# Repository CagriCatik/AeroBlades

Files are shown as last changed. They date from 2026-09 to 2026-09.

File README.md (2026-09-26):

# ⚔️ AeroBlades: 3D-Printed FPV Cruiser Fleet & Hybrid VTOL Systems







> **AeroBlades** is a unified hangar, master catalog, and flight guide for the high-performance family of 3D-printed mini-sized FPV cruisers and experimental hybrid VTOL aircraft designed by **Olivier_C** on [RCGroups](https://www.rcgroups.com/forums/showthread.php?4223695-Rifter-Sabre-Scimitar-mini-sized-FPV-cruisers).
>
> Inspired by the distinctive bladed weapons that give each airframe its name (*Urumi, Sabre, Scimitar, Sica, and Rifter*), **AeroBlades** standardizes all CAD models, 3D printing stage files, BOMs, slicing presets, and flight logs into a single comprehensive repository.
>
> Every project in this repository is organized into a standardized, production-ready directory layout:
> * 🖨️ **`3D_Print_Files/`**: Categorized by assembly stage (`01_Fuselage`, `02_Wings`, `03_Tail_and_Stabs` / `Nacelles`, `04_Internal_Plates`, `05_Canopy`, `Extras`).
> * 📐 **`CAD_Source_STEP/`** or **`CAD_Source_Fusion/`**: Parametric STEP and native Fusion 360 (`.f3d`) files for custom CAD modifications.
> * 🖼️ **`media/`**: High-resolution photography of assembled airframes and slicer bed placement guides.
> * 📊 **`*.ods`**: Master spreadsheets with print times, gram weights, and layer profiles.
> * 📦 **`archives/`**: Original source zip distribution packages preserved as pristine backups.

---

## ⚡ Quick Navigation

1. [📊 Master Fleet Comparison Matrix](#-master-fleet-comparison-matrix)
2. [🛸 Urumi](#1-urumi-experimental-hybrid-vtol--quadplane) — Experimental quad-motor tailsitter VTOL / Interceptor (571g)
3. [🛩️ Mini Rifter](#2-mini-rifter-ultra-compact-fpv-cruiser) — Ultra-compact single-pusher cruiser (314g)
4. [🛩️ Rifter 3](#3-rifter-3-high-endurance-v-tail-cruiser) — Third-generation long-endurance cruiser (430g)
5. [🗡️ Sabre](#4-sabre-high-speed-twin-tractor-plank) — Twin-tractor high-speed plank (476g)
6. [🦅 Scimitar 3](#5-scimitar-3-swept-wing-flying-wing) — Third-generation swept flying wing (438g)
7. [⚔️ Sica](#6-sica-flagship-twin-tractor-heavy-cruiser) — Flagship twin-tractor heavy cruiser with COB LEDs (746g)
8. [📦 Common Hardware Ecosystem](#-common-hardware-ecosystem) — SCM camera mounts, DJI O3 cages, canopy spring locks
9. [🔩 Fleet-Wide Carbon Spar Procurement Matrix](#-fleet-wide-carbon-spar-procurement-matrix)
10. [🖨️ Standardized Slicing Profiles Cheat Sheet](#-standardized-slicing-profiles-cheat-sheet)
11. [🛠️ Fleet Best Practices & Engineering Guides](#️-fleet-best-practices--engineering-guides)
12. [📂 Repository Directory Structure](#-repository-directory-structure)
13. [📌 Citation & Forum Thread](#-citation--forum-thread)

---

## 📊 Master Fleet Comparison Matrix

```mermaid
graph TD
    FLEET["⚔️ <b>AeroBlades 3D-Printed Fleet</b><br/><i>(Designed by Olivier_C)</i>"]
    
    FLEET --> PUSHER["<b>Single Pusher Cruisers</b>"]
    FLEET --> TWIN["<b>Twin Tractor Cruisers</b>"]
    FLEET --> VTOL["<b>Hybrid VTOL Systems</b>"]
    FLEET --> COMMON["<b>Hardware Ecosystem</b>"]
    
    PUSHER --> MR["🛩️ <b>Mini Rifter</b> (314g)<br/>Ultra-compact park cruiser"]
    PUSHER --> R3["🛩️ <b>Rifter 3</b> (430g)<br/>Long-endurance V-tail glider"]
    PUSHER --> SC3["🦅 <b>Scimitar 3</b> (438g)<br/>Swept acrobatic wing"]
    
    TWIN --> SAB["🗡️ <b>Sabre</b> (476g)<br/>High-speed carving plank (120+ km/h)"]
    TWIN --> SIC["⚔️ <b>Sica</b> (746g)<br/>Flagship heavy twin (COB LEDs)"]
    
    VTOL --> URU["🛸 <b>Urumi</b> (571g)<br/>Quad-motor tailsitter VTOL"]
    COMMON --> COM["📦 <b>Common Hardware</b><br/>SCM mounts, DJI O3 cages, locks"]
```

| Aircraft | Category | Propulsion | Plastic Wt. | Print Time | Carbon Spars | Controls | Best Suited For | Files / Project |
| :--- | :--- | :--- | :---: | :---: | :--- | :--- | :--- | :---: |
| [**Urumi**](#1-urumi-experimental-hybrid-vtol--quadplane) | Hybrid VTOL | Quad Motor (4× 2207–2806, 7" props) | **571 g** | 26h 30m | 4× 6×284mm | Differential Thrust (No control surfaces) | Vertical takeoff/landing, hover-to-cruise transition | [📂 `projects/Urumi/`](projects/Urumi/) |
| [**Mini Rifter**](#2-mini-rifter-ultra-compact-fpv-cruiser) | Compact Cruiser | Single Pusher (1806–2204, 4"–5" prop) | **314 g** | 19h 18m | Front: 6×600mm<br>Rear: 6×260mm | Ailerons + Stabs | Park flying, tight spaces, ultra-portability | [📂 `projects/Mini_Rifter/`](projects/Mini_Rifter/) |
| [**Rifter 3**](#3-rifter-3-high-endurance-v-tail-cruiser) | Long-Range Cruiser | Single Pusher (2207–2806, 6"–7" prop) | **430 g** | 31h 40m | Front: 8×800mm<br>Rear: 6×400mm<br>Fuselage: 2× 6×135mm | Ailerons + V-Tail | High-efficiency glide, long range, relaxed cruising | [📂 `projects/Rifter_3/`](projects/Rifter_3/) |
| [**Sabre**](#4-sabre-high-speed-twin-tractor-plank) | Fast FPV Plank | Twin Tractor (2× 1404–1806, 4"–5" props)| **476 g** | 45h 41m | Front: 6×680mm<br>Rear: 6×320mm | 2 Elevons | Low-level carving, high top speed, pitch locked | [📂 `projects/Sabre/`](projects/Sabre/) |
| [**Scimitar 3**](#5-scimitar-3-swept-wing-flying-wing)| Flying Wing | Single Pusher (2207–2306, 5"–6" prop) | **438 g** | 21h 02m | Main: 8×750mm<br>Front: 2× 6×150mm | 2 Elevons | High agility, zero fuselage drag, aerobatics | [📂 `projects/Scimitar_3/`](projects/Scimitar_3/) |
| [**Sica**](#6-sica-flagship-twin-tractor-heavy-cruiser) | Heavy Flagship | Twin Tractor (2× 2207–2806, 6"–7" props)| **746 g** | 39h 59m | Front: 8×1000mm<br>Rear: 6×700mm<br>Tail: 2× 8×330mm | Ailerons + Twin Rudders + Elevator | Max payload, gimbal mounts, night flights (COB LED) | [📂 `projects/Sica/`](projects/Sica/) |
| [**Common**](#-common-hardware-ecosystem) | Hardware Ecosystem | Modular (Canopy Locks, SCM, O3 Cages) | Variable | - | - | - | Universal hardware across all airframes | [📂 `projects/Common/`](projects/Common/) |

---

## 🛩️ Detailed Aircraft Profiles

### 1. Urumi: Experimental Hybrid VTOL / Quadplane





> **Urumi** is an experimental hybrid VTOL aircraft combining vertical helicopter hovering with high-speed wing-borne forward flight. Featuring four 22° dihedral wings, four brushless motors, a tilting servo camera, and **no moving control surfaces**, Urumi is steered entirely via differential thrust.

| Top View | Front View |
| :---: | :---: |
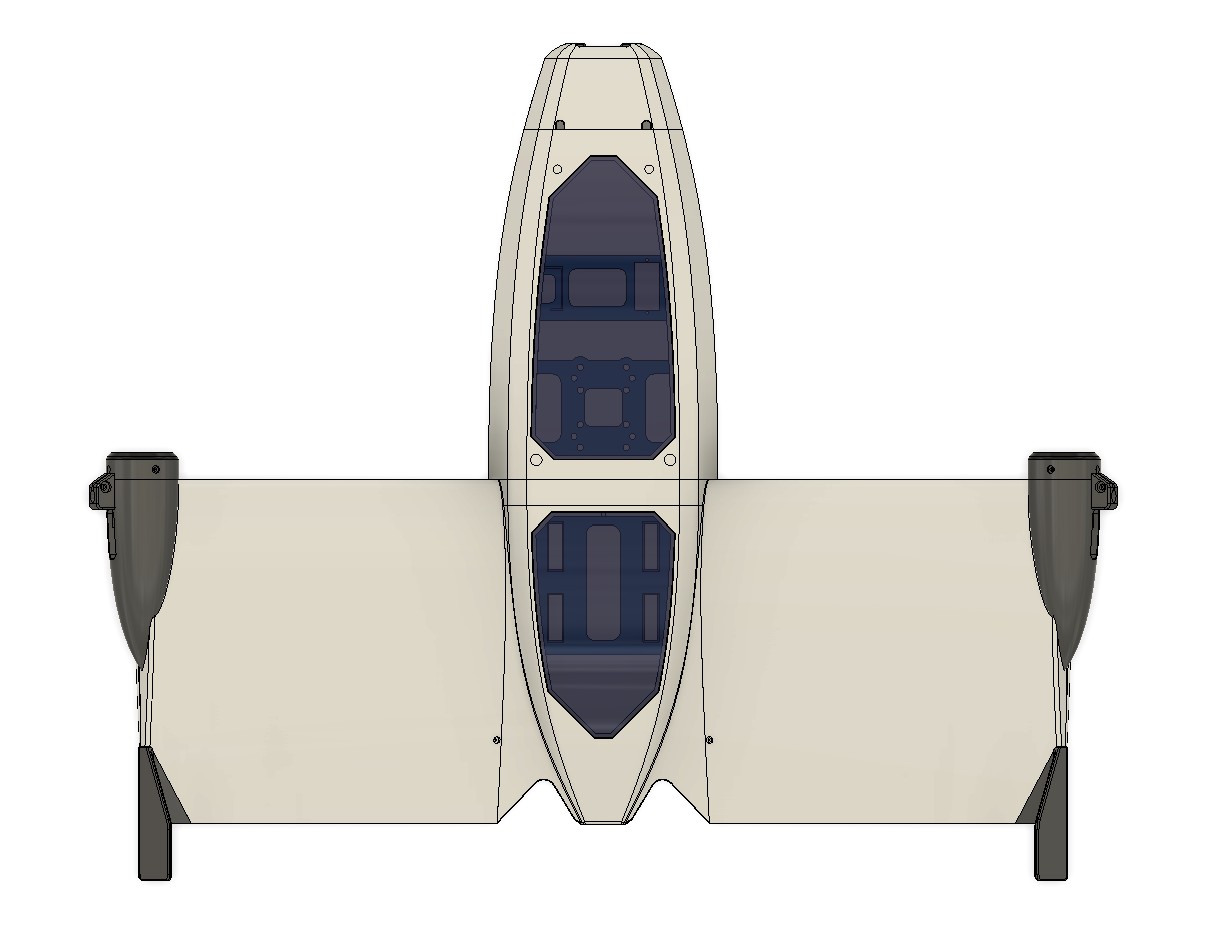
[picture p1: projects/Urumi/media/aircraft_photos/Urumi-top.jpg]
Urumi Top
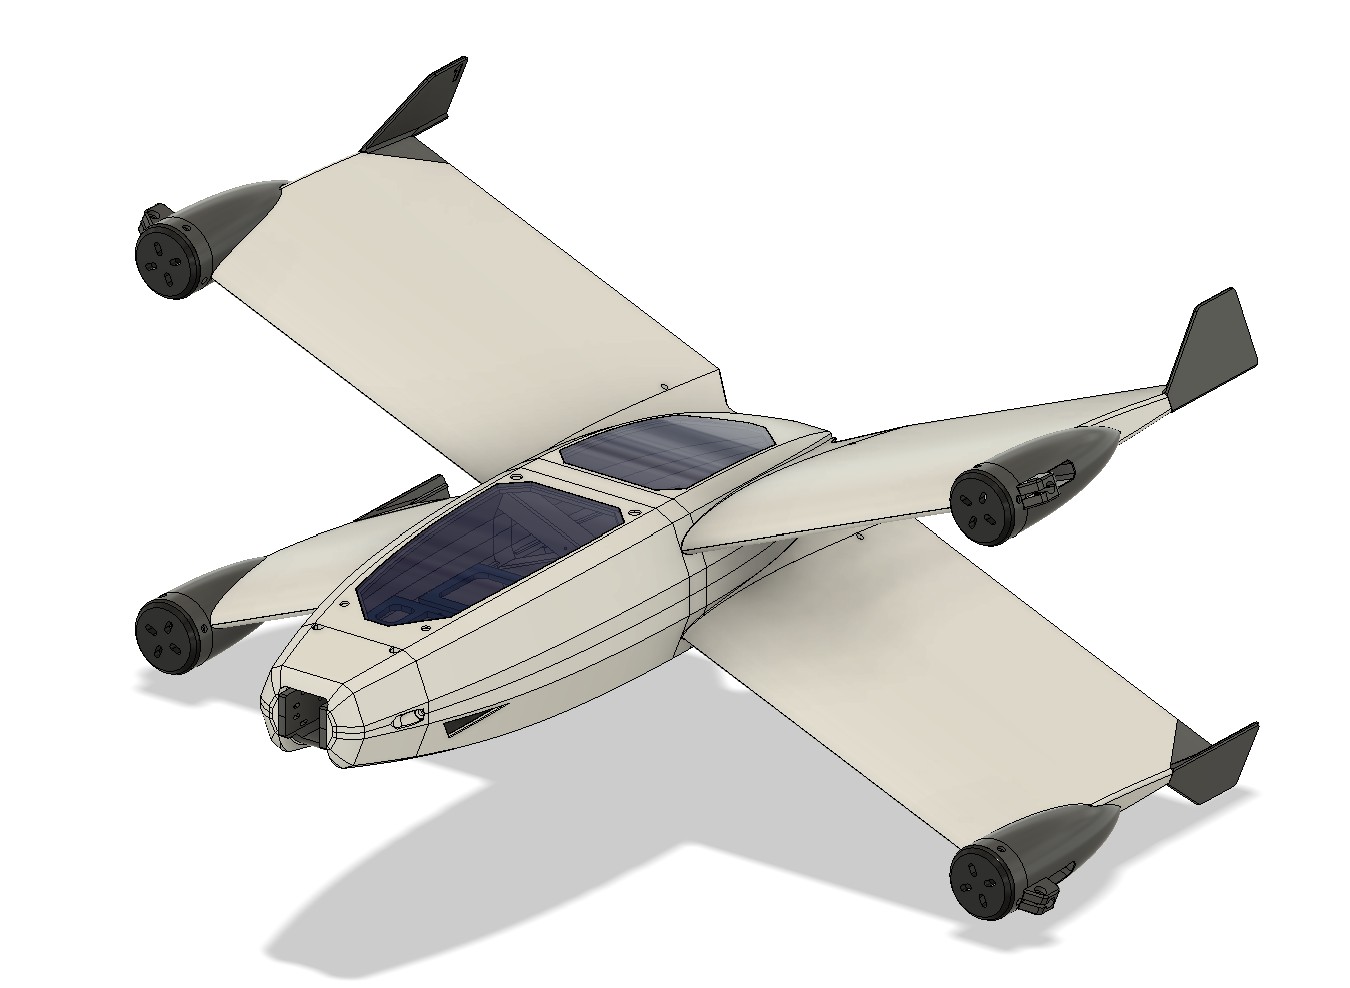
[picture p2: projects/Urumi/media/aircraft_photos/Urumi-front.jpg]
Urumi Front
|  |  |
| **Side Profile** | **Disassembled Airframe & Removable Wings** |
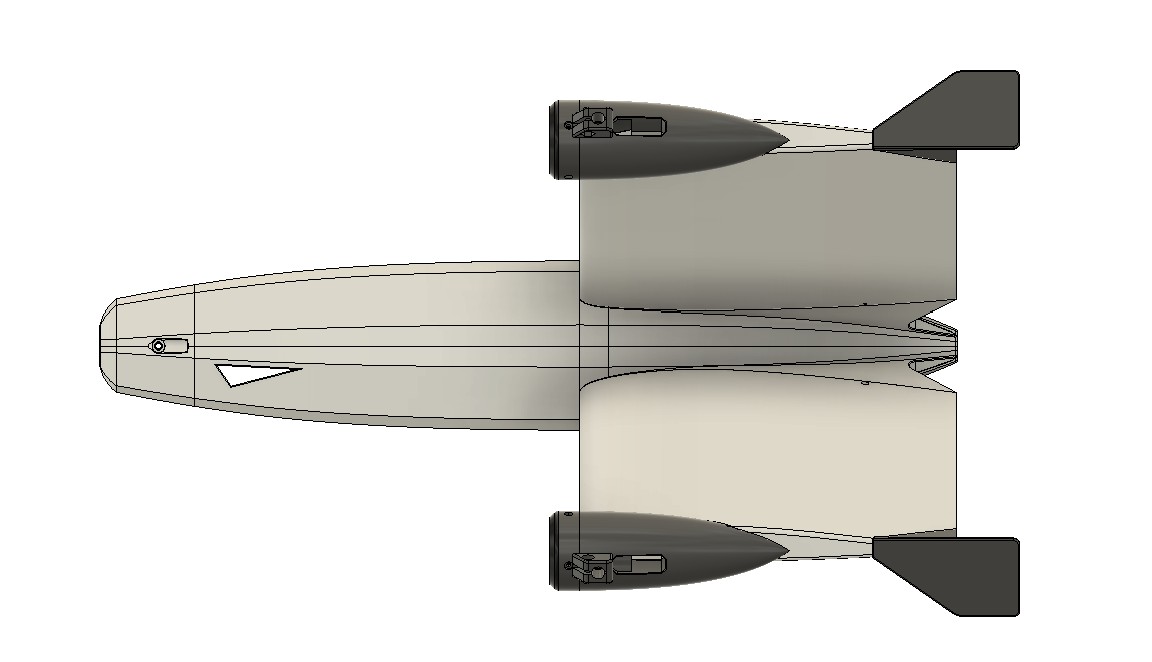
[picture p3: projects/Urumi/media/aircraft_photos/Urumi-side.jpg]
Urumi Side
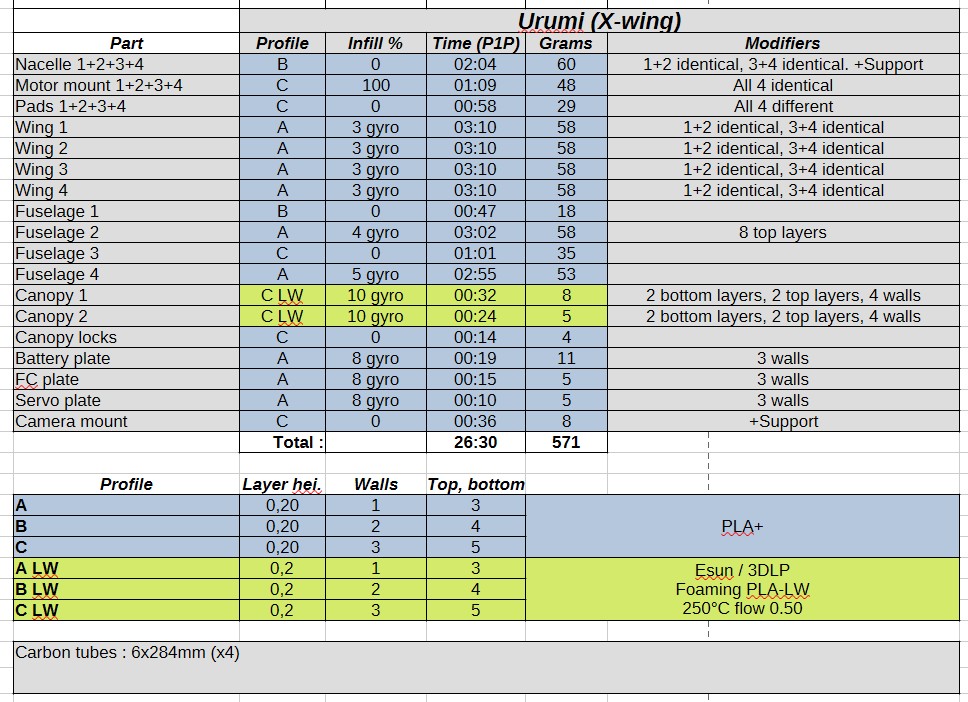
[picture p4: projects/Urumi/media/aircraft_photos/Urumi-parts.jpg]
Urumi Parts
|  |  |

* **Key Specifications**:
  * **Plastic Print Weight**: 571 g (Dry weight with FPV gear: 1035 g, AUW: ~1215 g with 4S 1500mAh)
  * **Print Time**: 26h 30m (Bambu Lab P1P)
  * **Propulsion**: 4× 2207 (1800–1950KV on 4S) or 2806.5 motors with 7" propellers
  * **Battery**: 4S 1500mAh 100C LiPo (~180g)
  * **Transition Airspeed**: 70 – 80 km/h
  * **Carbon Spars Required**: 4× 6.0 mm × 284 mm (forms central X-frame)
* **Available Resources**:
  * 🖨️ **3D Print Files**: [`projects/Urumi/3D_Print_Files/`](projects/Urumi/3D_Print_Files/)
    * `01_Fuselage/` — Fuselage 1, 2, 3, 4
    * `02_Wings/` — Wing 1-2, Wing 3-4 (with mirroring)
    * `03_Nacelles_and_Mounts/` — Nacelles 1-4, Motor mounts 1-4, Landing pads 1-4
    * `04_Internal_Plates/` — Battery plate, FC plate, Servo plate, Camera mount
    * `05_Canopy/` — Canopy 1 & 2, Canopy locks
    * `Extras/` — 0.5mm tighter motor mounts, Wing roots 1-4
  * 📐 **Slicer Placement Guides**: [`projects/Urumi/media/slicer_placement/`](projects/Urumi/media/slicer_placement/) (11 bed photos)
  * 🛠️ **CAD STEP Models**: [`projects/Urumi/CAD_Source_STEP/`](projects/Urumi/CAD_Source_STEP/) (19 STEP models)
  * 📚 **In-Depth Documentation Suite**: [`projects/Urumi/docs/`](projects/Urumi/docs/)
    * [01: Hardware Electronics & Configuration Software](projects/Urumi/docs/01_HARDWARE_ELECTRONICS.md)
    * [02: Hardware Parts, Mechanical Structure & Filaments](projects/Urumi/docs/02_HARDWARE_PARTS_AND_MECHANICAL.md)
    * [03: 3D Printing Guide & Master Slicer Profiles](projects/Urumi/docs/03_PRINT_GUIDE_AND_PROFILES.md)
    * [04: Airframe Assembly & Wiring Guide](projects/Urumi/docs/04_ASSEMBLY_AND_WIRING.md)
    * [05: INAV Hybrid VTOL Flight Manual](projects/Urumi/docs/05_INAV_FLIGHT_MANUAL.md)
    * [06: Designer Flight Logs & Video Transcripts](projects/Urumi/docs/06_DESIGNER_FLIGHT_LOGS_AND_VIDEO_TRANSCRIPTS.md)
  * 🎬 **Videos**: [Part 1 (Conception)](https://www.youtube.com/watch?v=R3-GTveqTRI) | [Part 2 (Crash Investigation)](https://www.youtube.com/watch?v=sHy94xdoC1A) | [Part 3 (Wind Handling)](https://www.youtube.com/watch?v=J87EU8D0PFA)

---

### 2. Mini Rifter: Ultra-Compact FPV Cruiser





> **Mini Rifter** is a scaled-down, ultra-portable edition of the Rifter cruiser platform. Designed for agile cruising, park flying, and efficient long endurance on small battery packs.

| Top View | Front View |
| :---: | :---: |
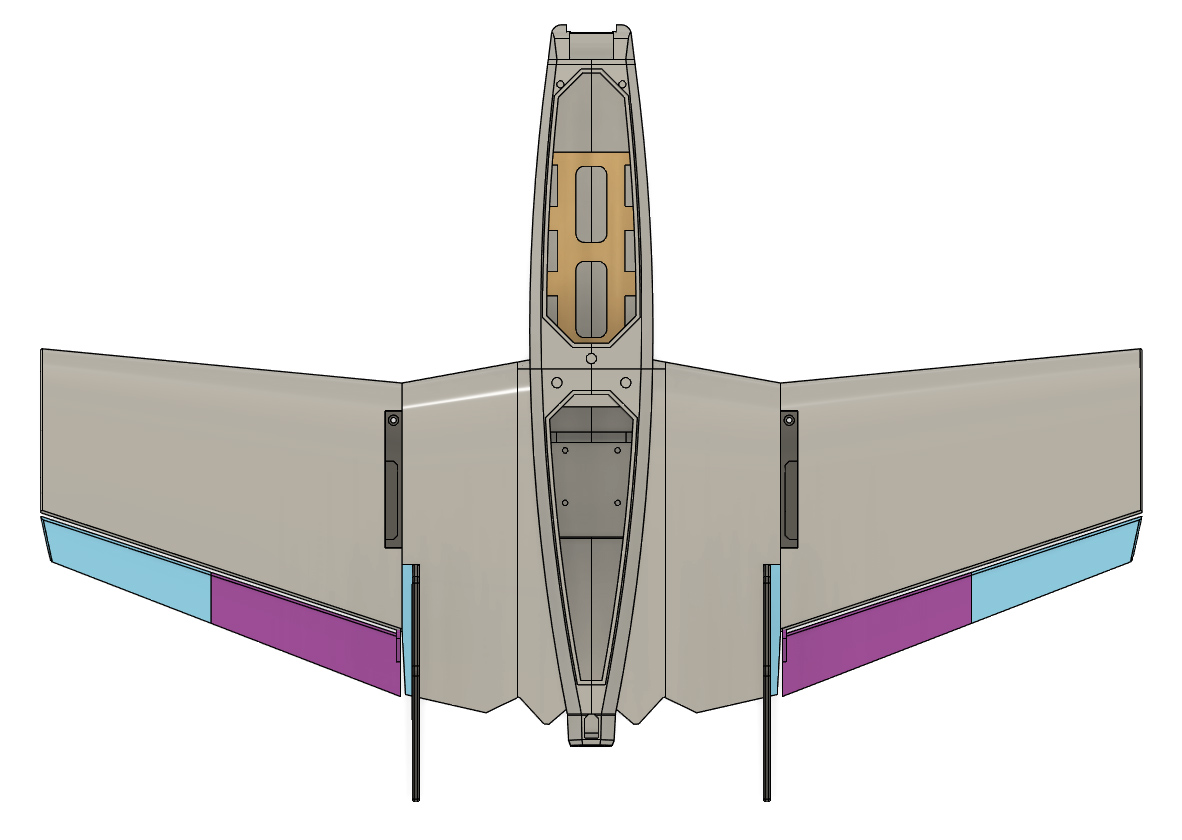
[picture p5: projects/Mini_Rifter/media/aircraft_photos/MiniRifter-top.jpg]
Mini Rifter Top
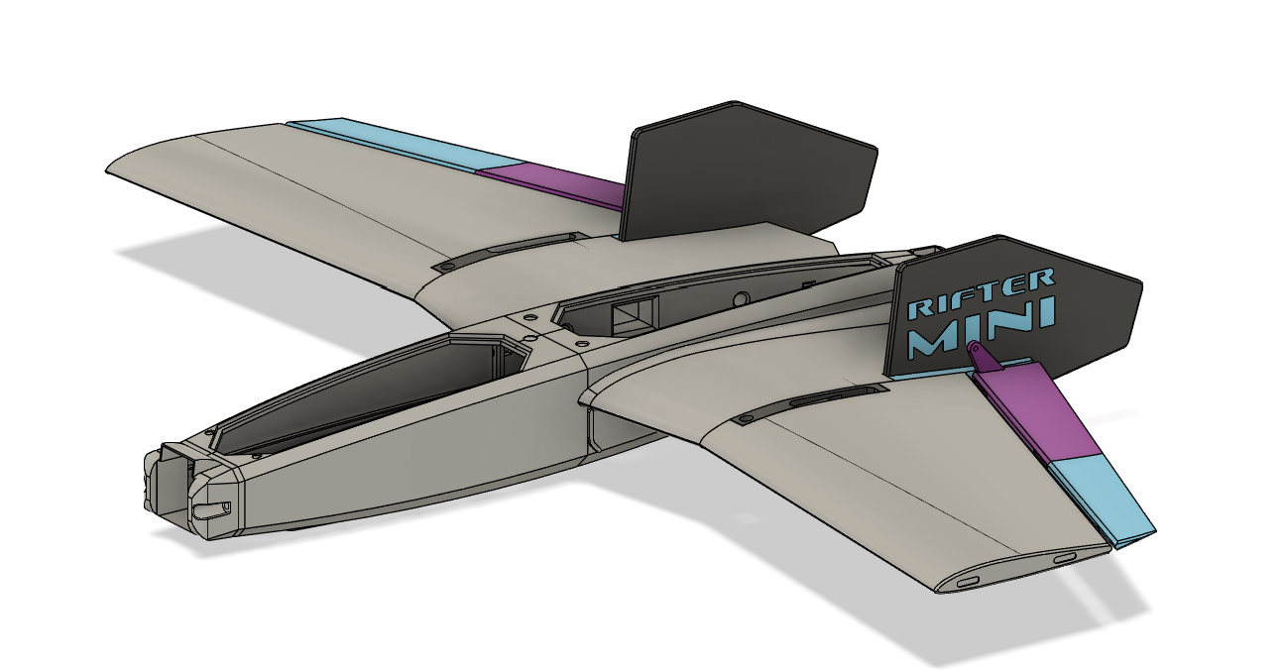
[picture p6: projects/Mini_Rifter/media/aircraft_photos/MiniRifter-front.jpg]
Mini Rifter Front
|  |  |
| **Side Profile** | **Disassembled Airframe & Parts** |
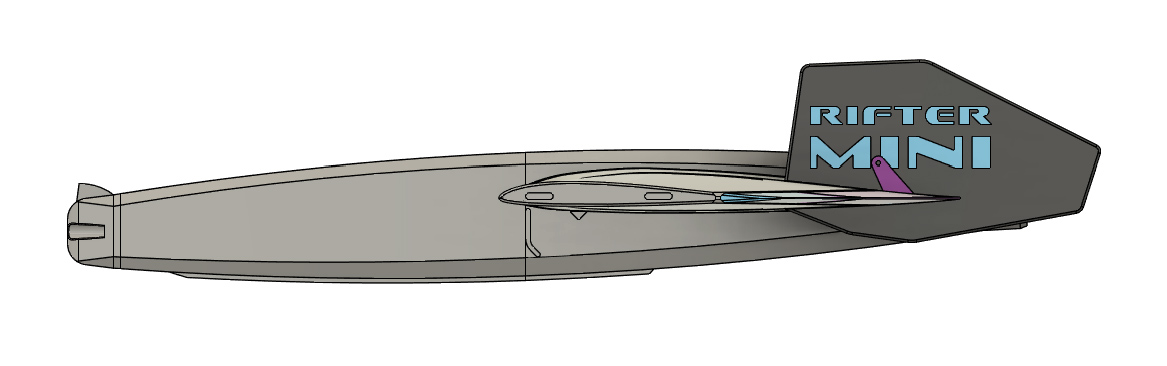
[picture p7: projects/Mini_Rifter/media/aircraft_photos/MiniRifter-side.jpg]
Mini Rifter Side
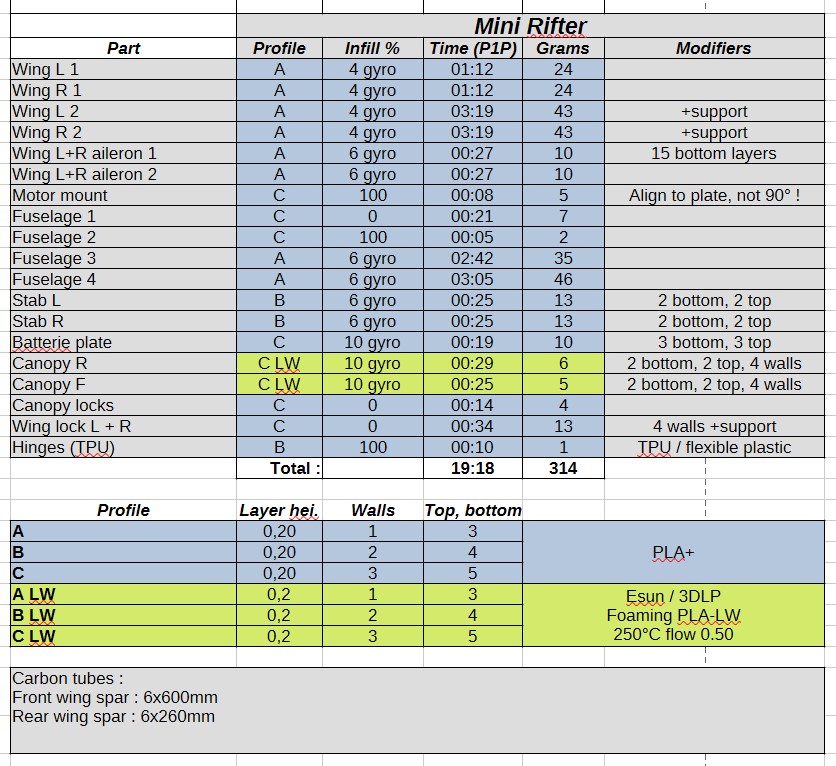
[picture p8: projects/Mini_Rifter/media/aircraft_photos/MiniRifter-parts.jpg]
Mini Rifter Parts
|  |  |

* **Key Specifications**:
  * **Plastic Print Weight**: 314 g
  * **Print Time**: 19h 18m (Bambu Lab P1P)
  * **Propulsion**: Single rear pusher motor (1806–2204), 4"–5" prop
  * **Battery**: 3S 18650 Li-ion pack or 3S/4S 1300–1500mAh LiPo
  * **Carbon Spars Required**: Front 6.0 mm × 600 mm, Rear 6.0 mm × 260 mm
* **Available Resources**:
  * 🖨️ **3D Print Files**: [`projects/Mini_Rifter/3D_Print_Files/`](projects/Mini_Rifter/3D_Print_Files/)
    * `01_Fuselage/` — Fuselage 1, 2, 3, 4, F3F4 pins
    * `02_Wings/` — Wings 1 & 2 (L/R), Ailerons 1 & 2 (L/R), Wing locks
    * `03_Tail_and_Stabs/` — Wing Stabs (L/R), Motor mount
    * `04_Internal_Plates/` — Battery plate, TPU hinges
    * `05_Canopy/` — Canopy F & R, Canopy locks
    * `Extras/` — SCM camera nose, no-holes nose, wingtips, external DJI O3 pod
  * 📐 **Slicer Placement Guides**: [`projects/Mini_Rifter/media/slicer_placement/`](projects/Mini_Rifter/media/slicer_placement/) (9 bed photos)
  * 🛠️ **CAD STEP Models**: [`projects/Mini_Rifter/CAD_Source_STEP/`](projects/Mini_Rifter/CAD_Source_STEP/) (16 STEP files)
  * 🎬 **Video**: [Mini Rifter Flight Test on YouTube](https://www.youtube.com/watch?v=fl-8yHl3snQ)

---

### 3. Rifter 3: High-Endurance V-Tail Cruiser





> **Rifter 3** is the mature, third-generation evolution of the Rifter single-motor pusher cruiser. Boasting a large high-aspect-ratio wing, dedicated fuselage bays, and modular carbon reinforcement, it delivers exceptional glide ratios and long-range cruising.

| Top View | Front View |
| :---: | :---: |
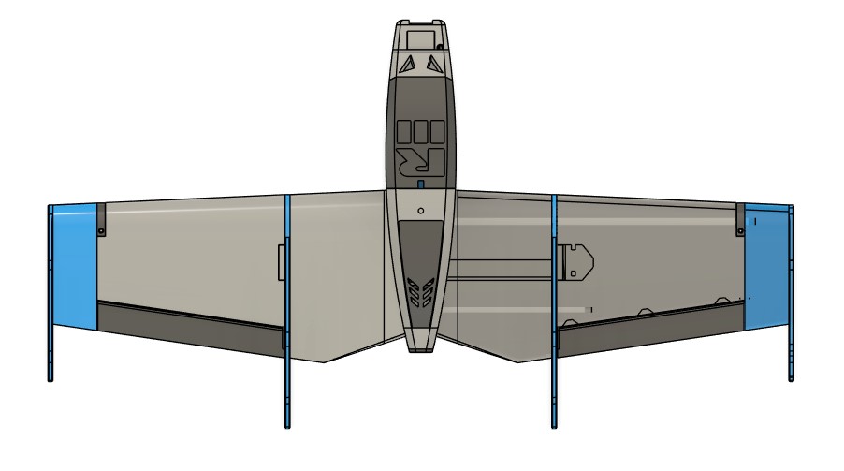
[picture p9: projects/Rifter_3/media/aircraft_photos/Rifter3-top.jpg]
Rifter 3 Top
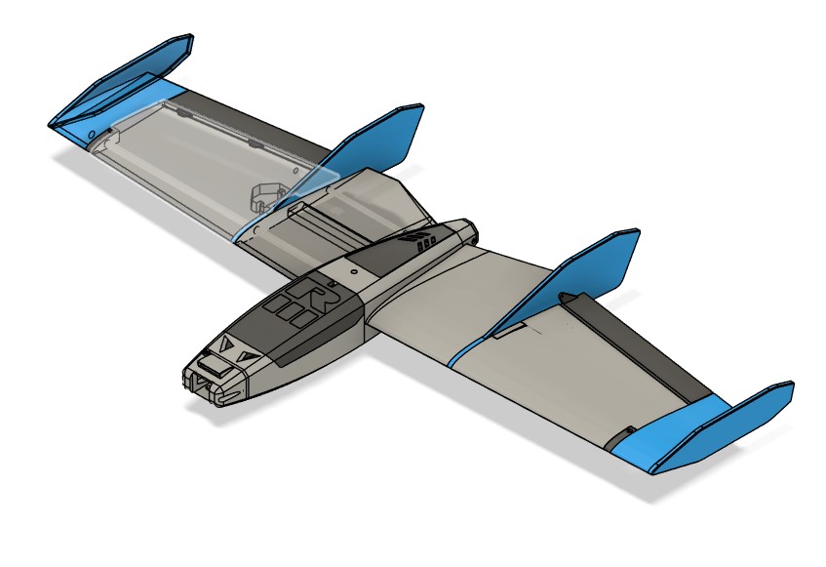
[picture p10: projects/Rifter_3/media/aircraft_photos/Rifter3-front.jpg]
Rifter 3 Front
|  |  |
| **Side Profile** | **Disassembled Airframe & Parts** |
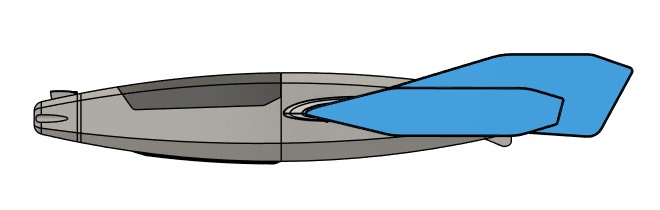
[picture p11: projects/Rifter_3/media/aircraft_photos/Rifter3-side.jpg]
Rifter 3 Side
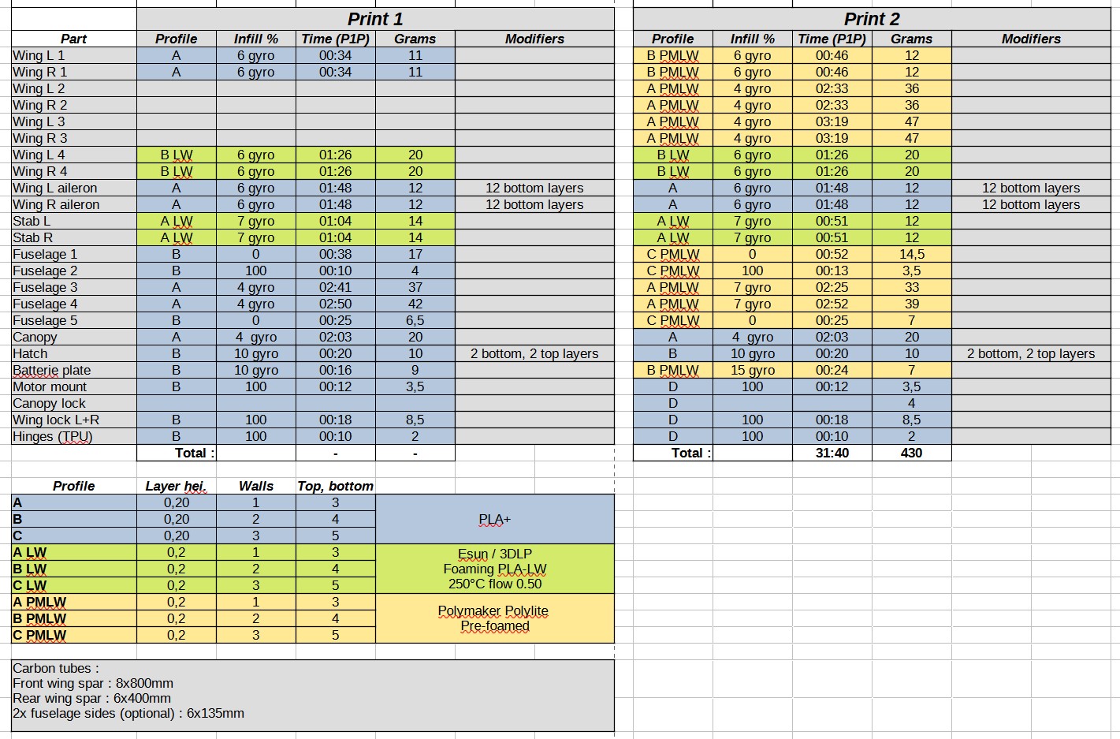
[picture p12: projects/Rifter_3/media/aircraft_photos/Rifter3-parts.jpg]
Rifter 3 Parts
|  |  |

* **Key Specifications**:
  * **Plastic Print Weight**: 430 g
  * **Print Time**: 31h 40m (Bambu Lab P1P)
  * **Propulsion**: Single rear pusher motor (2207–2806.5), 6"–7" prop
  * **Battery**: 4S 18650 / 21700 Li-ion pack (up to 4000–5000mAh) or 4S LiPo
  * **Carbon Spars Required**: Front 8.0 mm × 800 mm, Rear 6.0 mm × 400 mm, Fuselage (optional) 2× 6.0 mm × 135 mm
* **Available Resources**:
  * 🖨️ **3D Print Files**: [`projects/Rifter_3/3D_Print_Files/`](projects/Rifter_3/3D_Print_Files/)
    * `01_Fuselage/` — Fuselage 1 to 5, Hatch
    * `02_Wings/` — Wings 1 to 4 (L/R), Ailerons (L/R), Wing locks
    * `03_Tail_and_Stabs/` — V-tail Stabs, Motor mount
    * `04_Internal_Plates/` — Battery plate
    * `05_Canopy/` — Canopy, Canopy lock
    * `Extras/` — SCM camera nose, GPS plate
  * 📐 **Slicer Placement Guides**: [`projects/Rifter_3/media/slicer_placement/`](projects/Rifter_3/media/slicer_placement/) (13 bed photos)
  * 🛠️ **CAD STEP Models**: [`projects/Rifter_3/CAD_Source_STEP/`](projects/Rifter_3/CAD_Source_STEP/) (14 STEP files)
  * 🎬 **Videos**: [Rifter 3 Flight Test](https://www.youtube.com/watch?v=L3LojPVs68U) | [Rifter 2 Historic Video](https://www.youtube.com/watch?v=LL8X9GLXXWU)

---

### 4. Sabre: High-Speed Twin-Tractor Plank





> **Sabre** is a fast, aggressive twin-tractor "plank" cruiser. With twin counter-rotating tractor motors mounted on wing nacelles and an un-swept plank wing layout, Sabre delivers blistering acceleration, locked-in pitch stability, and thrilling low-altitude carving.

| Top View | Front View |
| :---: | :---: |
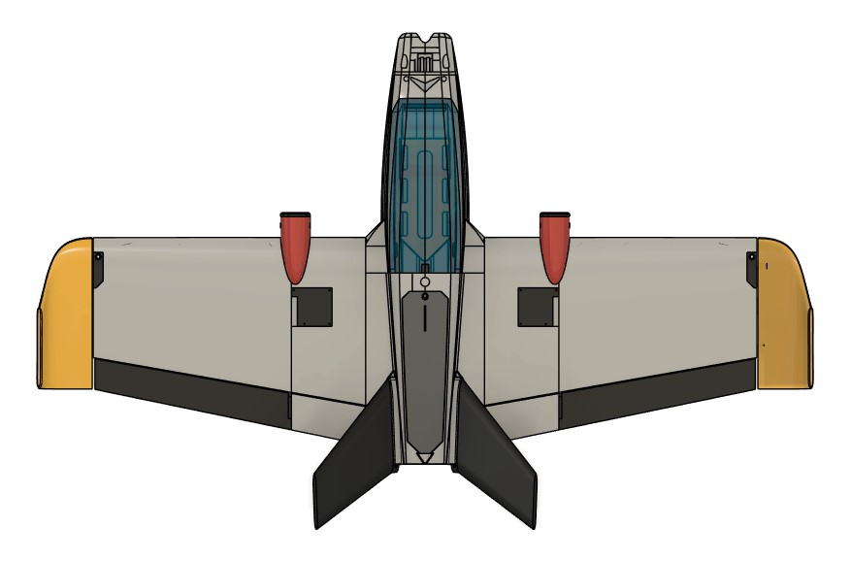
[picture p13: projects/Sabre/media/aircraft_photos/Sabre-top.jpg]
Sabre Top
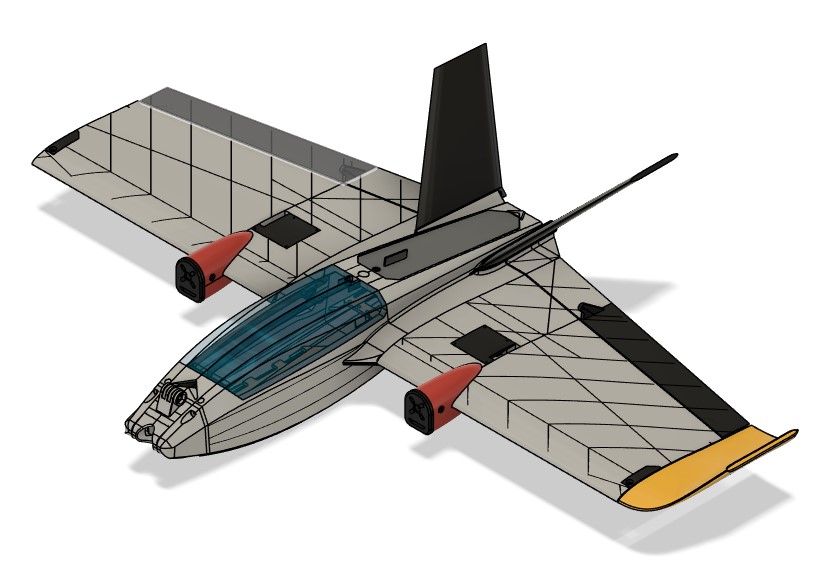
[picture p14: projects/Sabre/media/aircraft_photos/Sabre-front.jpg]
Sabre Front
|  |  |
| **Side Profile** | **Disassembled Airframe & Parts** |
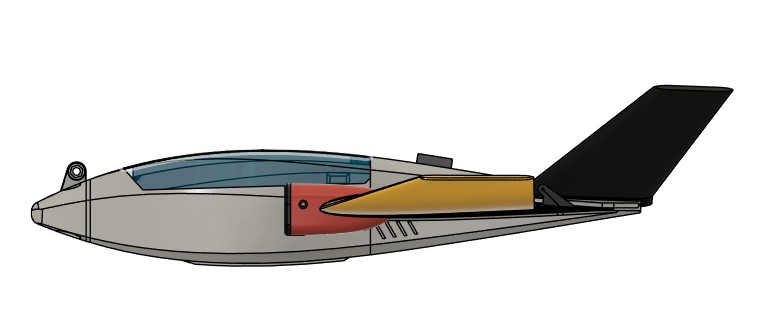
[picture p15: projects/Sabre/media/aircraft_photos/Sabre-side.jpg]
Sabre Side
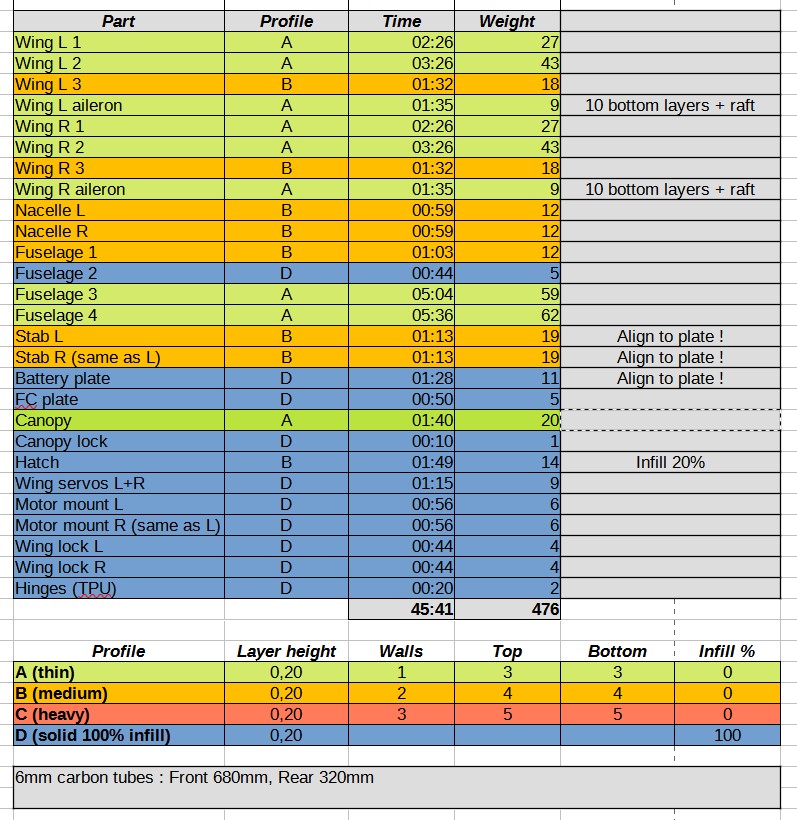
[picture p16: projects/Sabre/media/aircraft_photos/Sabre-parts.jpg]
Sabre Parts
|  |  |

* **Key Specifications**:
  * **Plastic Print Weight**: 476 g
  * **Print Time**: 45h 41m (Bambu Lab P1P)
  * **Propulsion**: Twin tractor motors (2× 1404–1806), 4"–5" counter-rotating props
  * **Battery**: 4S 1500–2200mAh LiPo or 4S 18650 Li-ion pack
  * **Carbon Spars Required**: Front 6.0 mm × 680 mm, Rear 6.0 mm × 320 mm
* **Available Resources**:
  * 🖨️ **3D Print Files**: [`projects/Sabre/3D_Print_Files/`](projects/Sabre/3D_Print_Files/)
    * `01_Fuselage/` — Fuselage 1 to 4, Hatch
    * `02_Wings/` — Wings 1 to 3 (L/R), Ailerons, Locks, Servos
    * `03_Nacelles_and_Mounts/` — Nacelles (L/R), Motor mounts, Stabs
    * `04_Internal_Plates/` — Battery plate, FC plate, TPU hinges
    * `05_Canopy/` — Canopy, Canopy lock
    * `Extras/` — Dedicated GoPro nose, SCM nose
  * 📐 **Slicer Placement Guides**: [`projects/Sabre/media/slicer_placement/`](projects/Sabre/media/slicer_placement/) (21 bed photos)
  * 🛠️ **Parametric Fusion 360 Source Files**: [`projects/Sabre/CAD_Source_Fusion/`](projects/Sabre/CAD_Source_Fusion/) (18 native `.f3d` files)
  * 🎬 **Video**: [Sabre Flight Demonstration on YouTube](https://www.youtube.com/watch?v=Vm1uSv3ZKd4)

---

### 5. Scimitar 3: Swept-Wing Flying Wing





> **Scimitar 3** is a high-performance 3D-printed swept flying wing powered by a central pusher motor. Engineered for clean laminar airflow, fast cruise speeds, and high aerobatic agility with zero fuselage drag.

| Top View | Front View |
| :---: | :---: |
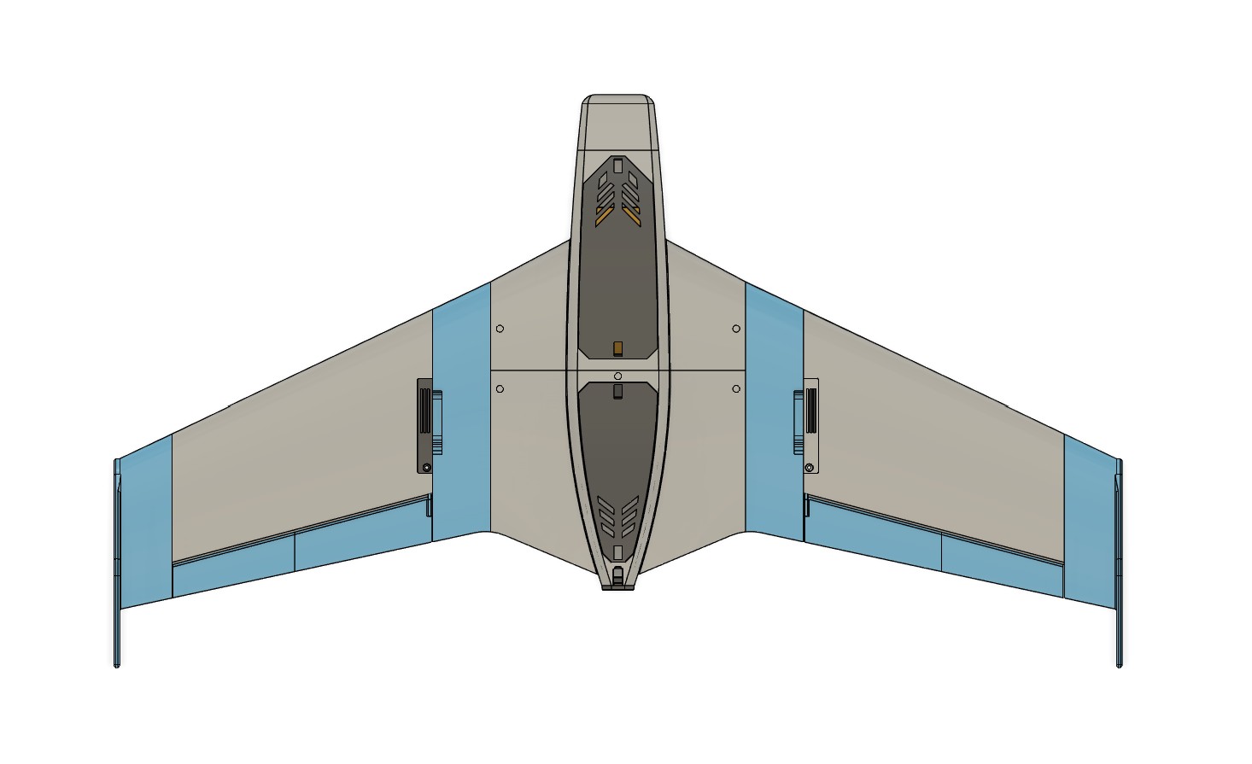
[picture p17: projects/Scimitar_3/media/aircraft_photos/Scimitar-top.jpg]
Scimitar 3 Top
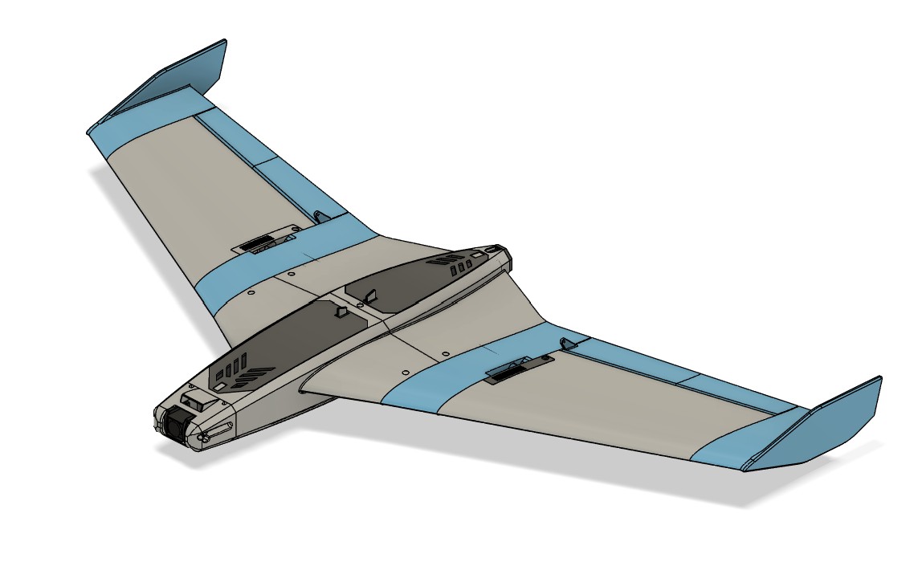
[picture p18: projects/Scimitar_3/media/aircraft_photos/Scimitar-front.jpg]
Scimitar 3 Front
|  |  |
| **Side Profile** | **Disassembled Airframe & Parts** |
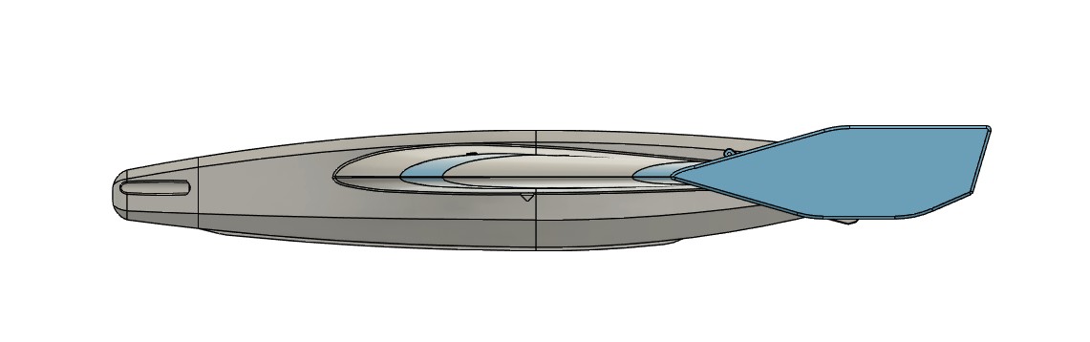
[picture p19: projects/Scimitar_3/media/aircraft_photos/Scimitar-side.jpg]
Scimitar 3 Side
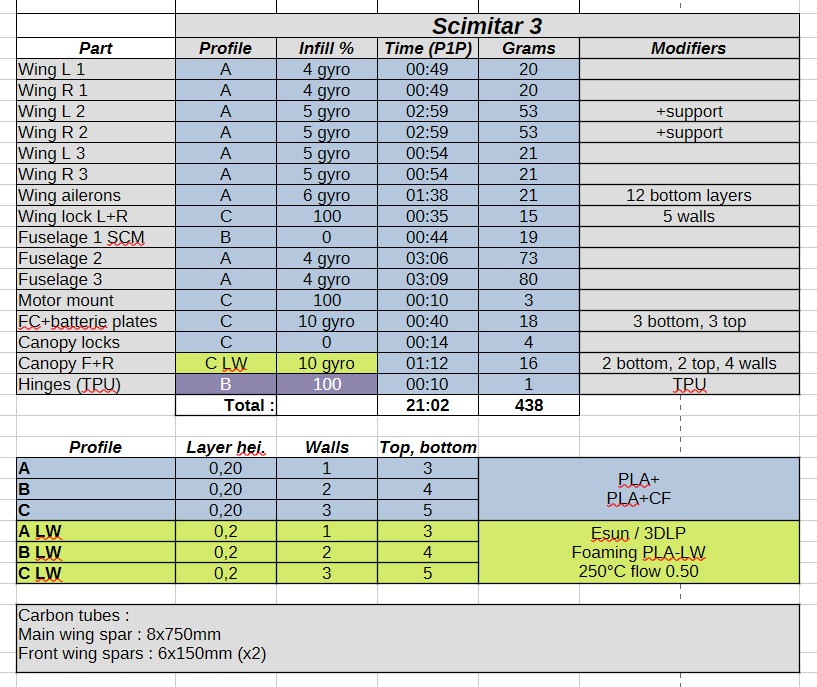
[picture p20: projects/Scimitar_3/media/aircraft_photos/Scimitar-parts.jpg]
Scimitar 3 Parts
|  |  |

* **Key Specifications**:
  * **Plastic Print Weight**: 438 g
  * **Print Time**: 21h 02m (Bambu Lab P1P)
  * **Propulsion**: Single rear pusher motor (2207–2306), 5"–6" prop
  * **Battery**: 4S 1500–2200mAh LiPo or 4S 18650 Li-ion pack
  * **Carbon Spars Required**: Main wing spar 8.0 mm × 750 mm, Front wing spars 2× 6.0 mm × 150 mm
* **Available Resources**:
  * 🖨️ **3D Print Files**: [`projects/Scimitar_3/3D_Print_Files/`](projects/Scimitar_3/3D_Print_Files/)
    * `01_Fuselage/` — Fuselage 1, 1 SCM, 2, 3
    * `02_Wings/` — Wings 1 to 3 (L/R), Elevons, Wing locks
    * `03_Motor_Mount/` — Motor mount 4mm
    * `04_Internal_Plates/` — Battery plate, FC plate, TPU hinges
    * `05_Canopy/` — Canopy F & R, Canopy locks
    * `Extras/` — Extended wingtips (+25mm), centering pin, text canopies
  * 📐 **Slicer Placement Guides**: [`projects/Scimitar_3/media/slicer_placement/`](projects/Scimitar_3/media/slicer_placement/) (11 bed photos)
  * 🛠️ **CAD STEP Models**: [`projects/Scimitar_3/CAD_Source_STEP/`](projects/Scimitar_3/CAD_Source_STEP/) (10 STEP files)
  * 🎬 **Video**: [Scimitar Flying Wing Flight Demonstration](https://www.youtube.com/watch?v=LZn1OF9eK5k)

---

### 6. Sica: Flagship Twin-Tractor Heavy Cruiser





> **Sica** is the flagship heavy long-range cruiser of the fleet. Featuring twin forward tractor motors, a generous fuselage payload cabin, twin vertical stabilizers, and full night-flight COB LED internal channels, Sica is the ultimate endurance platform.

| Top View | Front View |
| :---: | :---: |
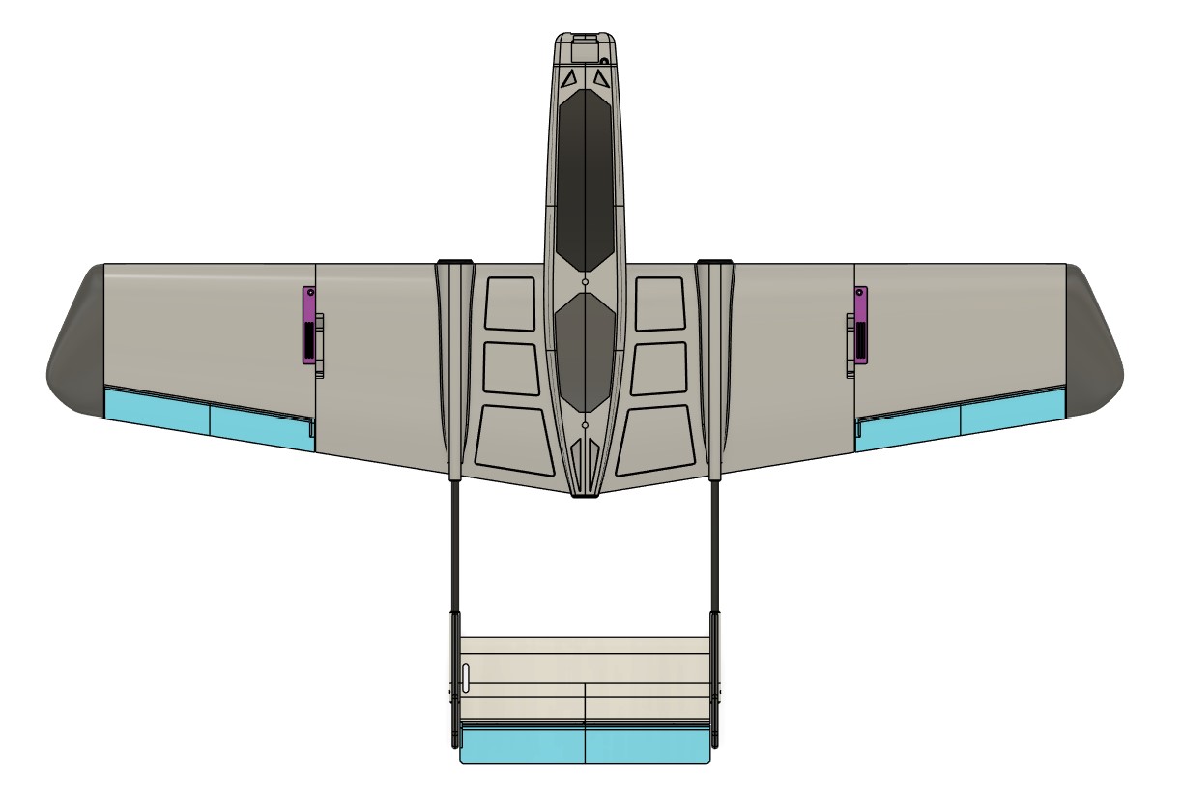
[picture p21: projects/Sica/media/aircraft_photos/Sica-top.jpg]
Sica Top
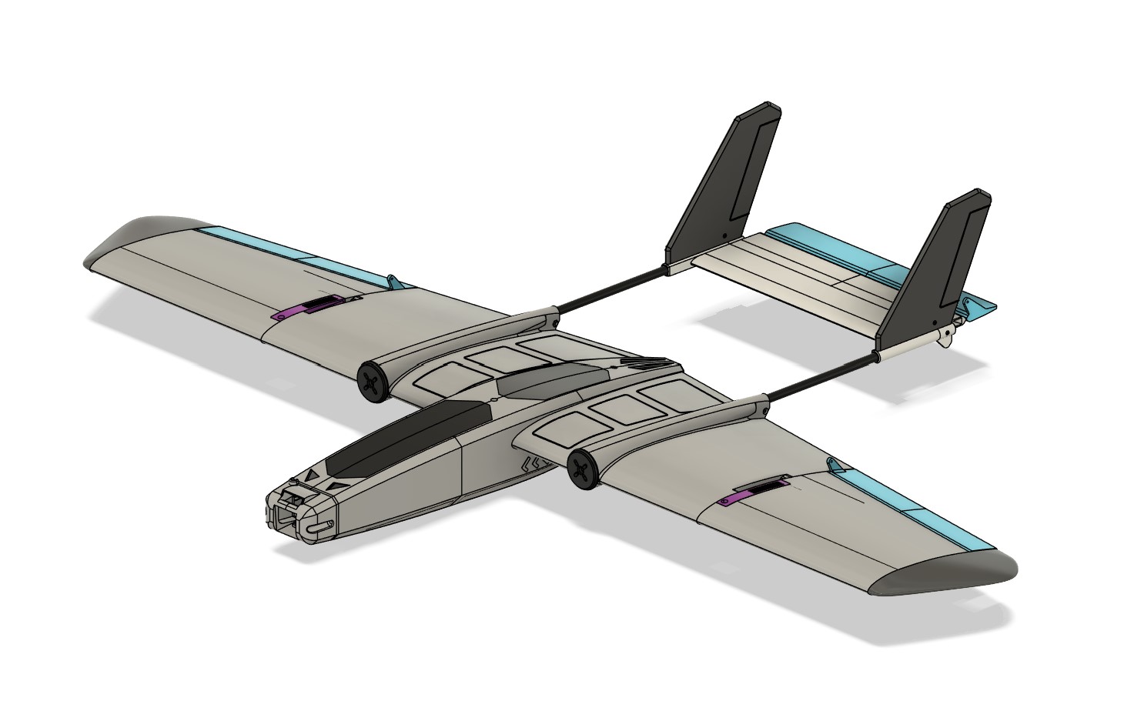
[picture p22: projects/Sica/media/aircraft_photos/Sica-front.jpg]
Sica Front
|  |  |
| **Side Profile** | **Disassembled Airframe & Parts** |
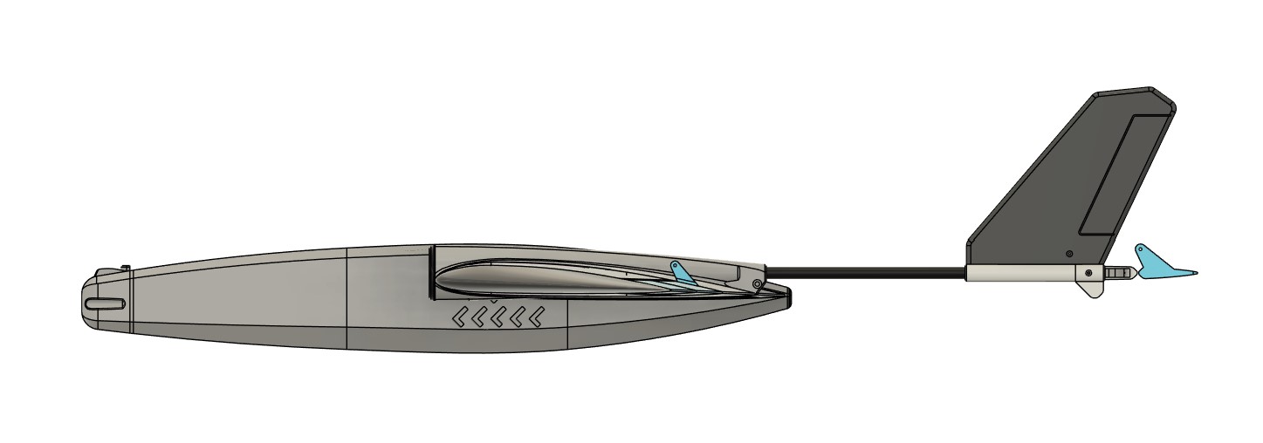
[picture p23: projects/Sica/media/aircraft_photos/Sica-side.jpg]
Sica Side
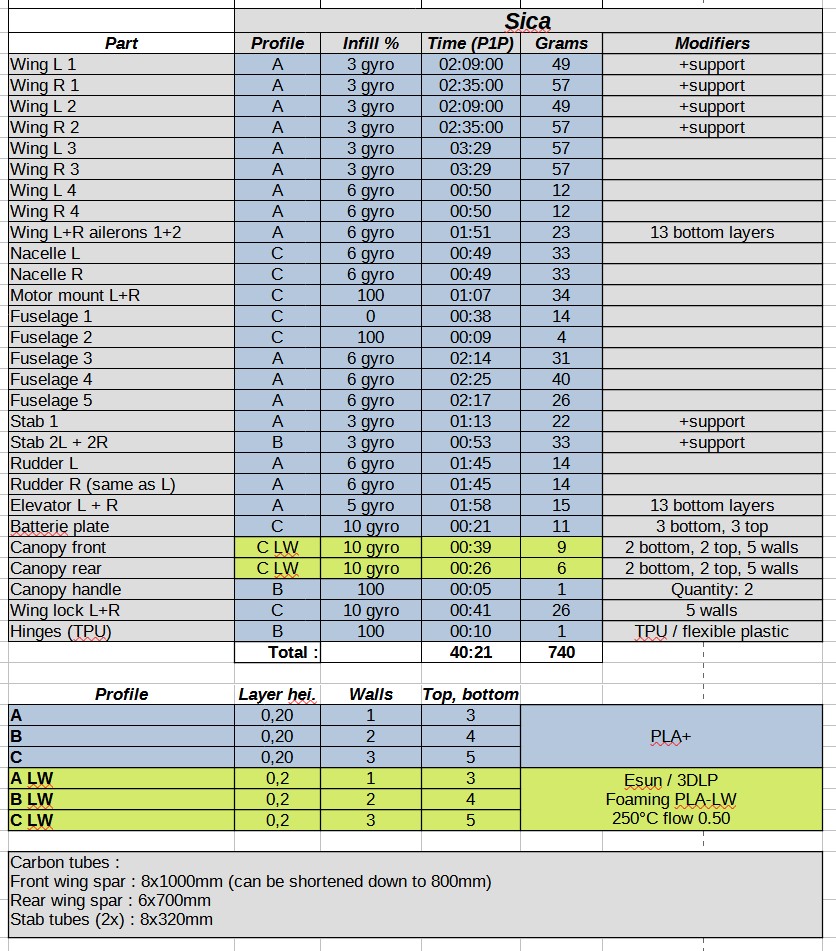
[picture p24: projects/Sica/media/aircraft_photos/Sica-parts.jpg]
Sica Parts
|  |  |

* **Key Specifications**:
  * **Plastic Print Weight**: 746 g
  * **Print Time**: 39h 59m (Bambu Lab P1P)
  * **Propulsion**: Twin tractor motors (2× 2207–2806.5), 6"–7" props
  * **Battery**: 4S 21700 4000–8000mAh Li-ion pack or large 4S LiPo
  * **Carbon Spars Required**: Front wing spar 8.0 mm × 1000 mm (or 800mm), Rear spar 6.0 mm × 700 mm, Tail stabs 2× 8.0 mm × 330 mm
* **Available Resources**:
  * 🖨️ **3D Print Files**: [`projects/Sica/3D_Print_Files/`](projects/Sica/3D_Print_Files/)
    * `01_Fuselage/` — Fuselage 1 to 5
    * `02_Wings/` — Wings 1 to 4 (L/R), Ailerons 1 & 2 (L/R), Wing locks
    * `03_Tail_and_Nacelles/` — Nacelles, Motor mounts, Stabs 1 & 2, Rudders, Elevators
    * `04_Internal_Plates/` — Battery plate, TPU hinges
    * `05_Canopy/` — Canopy Front & Rear, Canopy handles
    * `Extras/` — HEQ G-Port gimbal, O3 Pan/Tilt dome, COB LED suites
  * 📐 **Slicer Placement Guides**: [`projects/Sica/media/slicer_placement/`](projects/Sica/media/slicer_placement/) (20 bed photos)
  * 🛠️ **CAD STEP Models**: [`projects/Sica/CAD_Source_STEP/`](projects/Sica/CAD_Source_STEP/) (21 STEP models + `Sica v243.step`)
  * 🎬 **Videos**: [New Twin Tractor (Sica Introduction)](https://www.youtube.com/watch?v=HihsU5iFMYI) | [Neon Nights (COB LED Night Flight)](https://www.youtube.com/watch?v=hPF_NwX6mRE)

---

## 📦 Common Hardware Ecosystem




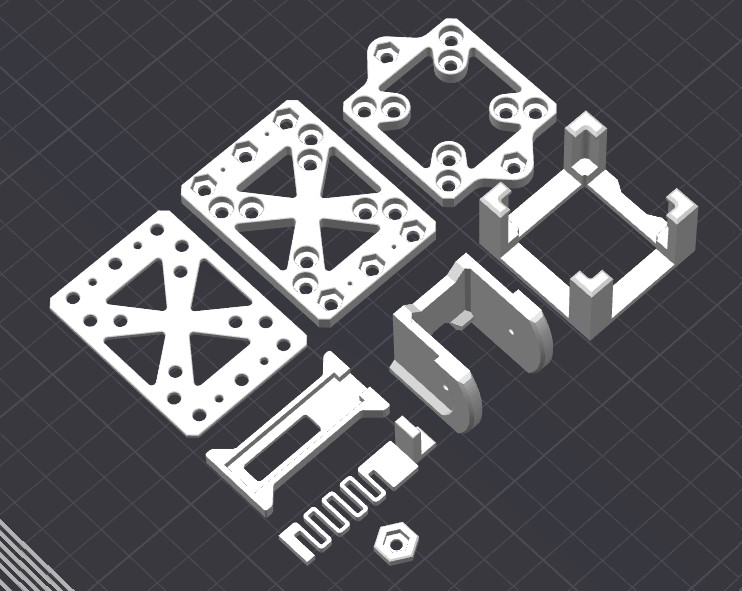
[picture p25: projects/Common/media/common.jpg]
Common Hardware


The [`projects/Common/`](projects/Common/) directory contains universal components shared across all aircraft:

1. **🔒 Canopy Spring Locks (`01_Canopy_Spring_Locks/`)**:
   Standardized tool-free snap latches (`Canopy spring Lock 1.3mf` & `2.3mf`) used on all canopies.
2. **📹 DJI O3 Air Unit Cage & Mounts (`02_DJI_O3_Mounts/`)**:
   Vibration-isolated camera cage (`DJI O3 cage 1.3mf`, `2.3mf`) and ventilated air unit VTX heatsink bracket (`DJI O3 VTX mount.3mf`).
3. **🎥 Standard Camera Mount (SCM) (`03_Standard_Camera_Mounts_SCM/`)**:
   Universal swappable nose blocks (`DJI O3 Cam mount.3mf`, `HDZero Micro Cam mount.3mf`, `Walksnail Cam mount.3mf`) for modern digital FPV cameras.
4. **⚡ Universal Flight Controller Trays & Hardware (`04_Universal_FC_Plates_and_Hardware/`)**:
   FC mounting plates (`FC plate 1-4`) and threaded M3 knurl brass insert adapters (`M3 knurl.3mf`).

---

## 🔩 Fleet-Wide Carbon Spar Procurement Matrix

This table aggregates all carbon fiber tube requirements across all aircraft, making it easy to purchase raw stock:

| Aircraft | Tube Outer Diameter | Length | Quantity Required | Purpose |
| :--- | :---: | :---: | :---: | :--- |
| **Urumi** | 6.0 mm | 284 mm | 4 | Central X-frame spars |
| **Mini Rifter** | 6.0 mm | 600 mm | 1 | Main wing spar |
| | 6.0 mm | 260 mm | 1 | Rear wing spar |
| **Rifter 3** | 8.0 mm | 800 mm | 1 | Main wing spar |
| | 6.0 mm | 400 mm | 1 | Rear wing spar |
| | 6.0 mm | 135 mm | 2 (optional) | Fuselage side stiffeners |
| **Sabre** | 6.0 mm | 680 mm | 1 | Main wing spar |
| | 6.0 mm | 320 mm | 1 | Rear wing spar |
| **Scimitar 3** | 8.0 mm | 750 mm | 1 | Main wing spar |
| | 6.0 mm | 150 mm | 2 | Forward wing spars |
| **Sica** | 8.0 mm | 1000 mm (or 800mm) | 1 | Main wing spar |
| | 6.0 mm | 700 mm | 1 | Rear wing spar |
| | 8.0 mm | 330 mm | 2 | Tail stabilizer spars |

---

## 🖨️ Standardized Slicing Profiles Cheat Sheet

All models in this fleet are tuned for 0.4mm nozzles, 0.20mm layer heights, and the standard Bambu Studio / OrcaSlicer profile conventions established by Olivier_C:

| Profile Code | Profile Name | Wall Loops | Top / Bottom Layers | Infill % & Pattern | Standard Material | Primary Use Cases |
| :--- | :--- | :---: | :---: | :---: | :--- | :--- |
| **Profile A** | Thin / Light | 1 | 3 / 3 | 3%–6% Gyroid | PLA+ / Pre-foamed LW | Wings, ailerons, main fuselage cabins |
| **Profile B** | Medium | 2 | 4 / 4 | 0%–10% Gyroid | PLA+ | Nose bays, tail cones, nacelles |
| **Profile C** | Heavy / Structural | 3 | 5 / 5 | 0% or 10% Gyroid | PLA+ | Landing pads, battery trays, wing locks, camera brackets |
| **Profile D** | Solid Retention | 3–5 | 5 / 5 | 100% Solid | PLA+ / PETG | Motor mounts, servo mounts, hinge pins |
| **Profile LW** | Active Foaming | 1–4 | 2 / 2 | 10% Gyroid | Foaming LW-PLA (250°C, 0.50 flow) | Lightweight aerodynamic canopies, tail stabs |
| **TPU** | Flexible | 2–3 | 4 / 4 | 100% Solid | Flexible TPU 95A | Integrated control surface hinges |

---

## 🛠️ Fleet Best Practices & Engineering Guides

For comprehensive engineering standards across materials, 3D printing parameters, electronics, and avionics, refer to the dedicated [`best_practices/`](best_practices/) documentation suite:

* 🧪 [**01: Material Selection & Filaments**](best_practices/01_MATERIALS_AND_FILAMENT_SELECTION.md) — Mechanical and thermal evaluation of PLA+, Aero ASA (LW-ASA), LW-PLA, PETG, and TPU 95A.
* 🖨️ [**02: 3D Printing & Slicer Setup**](best_practices/02_3D_PRINTING_AND_SLICER_SETUP.md) — The thin-wall Gyroid internal truss philosophy, hole shrinkage compensation, and bed adhesion.
* ⚡ [**03: Electronics, Propulsion & Power**](best_practices/03_ELECTRONICS_PROPULSION_AND_POWER.md) — Motor stator & KV sizing, counter-rotating twins, ESC capacitor filtering, and LiPo vs 21700 Li-ion batteries.
* 📡 [**04: Avionics, FPV & RF Integration**](best_practices/04_AVIONICS_FPV_AND_RF_INTEGRATION.md) — Flight controller soft-mounting, GPS/Compass EMI isolation, DJI O3 cooling/dampening, and ELRS antenna layout.
* 📖 [**05: References, Citations & Authoritative Sources**](best_practices/05_REFERENCES_AND_CITATIONS.md) — Empirical research (CNC Kitchen, Mooch), manufacturer TDS (colorFabb, Polymaker), and protocol documentation (ELRS, INAV).

---

## 📂 Repository Directory Structure

```
AeroBlades/
├── README.md                                  # AeroBlades Fleet Portal, Catalog & Master Guide (this file)
│
├── 📂 best_practices/                         # Engineering guides (Materials, Slicing, Electronics, FPV)
│   ├── 01_MATERIALS_AND_FILAMENT_SELECTION.md # Deep dive: PLA+, Aero ASA, LW-PLA, PETG, TPU
│   ├── 02_3D_PRINTING_AND_SLICER_SETUP.md     # Gyroid truss infill, spar tolerances, bed adhesion
│   ├── 03_ELECTRONICS_PROPULSION_AND_POWER.md # Motor/ESC sizing, LiPo vs Li-ion, capacitor filtering
│   ├── 04_AVIONICS_FPV_AND_RF_INTEGRATION.md  # INAV, GPS hygiene, digital FPV, antenna separation
│   ├── 05_REFERENCES_AND_CITATIONS.md         # Citations, CNC Kitchen tests, Mooch battery tests, TDS
│   └── README.md                              # Best practices index & 5 Golden Rules
│
├── 📂 projects/                               # All 7 standardized aircraft & hardware projects
│   ├── Common/                                # Shared canopy locks, DJI O3 cages, SCM mounts
│   ├── Mini_Rifter/                           # Mini Rifter cruiser files & README
│   ├── Rifter_3/                              # Rifter 3 cruiser files & README
│   ├── Sabre/                                 # Sabre twin-tractor plank files & README
│   ├── Scimitar_3/                            # Scimitar 3 swept flying wing files & README
│   ├── Sica/                                  # Sica heavy twin-tractor cruiser files & README
│   └── Urumi/                                 # Urumi hybrid VTOL files, docs & README
│
└── 📂 archives/                               # Backup storage of original release zip packages
    ├── Common.zip                             # Shared components across airframes
    ├── Mini Rifter.zip                        # Mini Rifter cruiser files
    ├── Rifter3.zip                            # Rifter 3 cruiser files
    ├── Sabre.zip                              # Sabre cruiser files
    ├── Scimitar3.zip                          # Scimitar 3 cruiser files
    ├── Sica.zip                               # Sica cruiser files
    └── Urumi.zip                              # Original Urumi release archive
```

---

## 📌 Citation & Forum Thread

The **AeroBlades** aircraft family originates from **Olivier_C**'s groundbreaking work on 3D-printed mini-sized FPV cruisers:

* **Primary Project Thread & Citation:**  
  👉 [RCGroups: Rifter, Sabre, Scimitar : mini-sized FPV cruisers](https://www.rcgroups.com/forums/showthread.php?4223695-Rifter-Sabre-Scimitar-mini-sized-FPV-cruisers)  
  *Author:* **Olivier_C** on RCGroups.com
* **Standardized Fleet Projects (`projects/`):**  
  * [`projects/Urumi/`](projects/Urumi/) — Experimental hybrid VTOL / Quadplane
  * [`projects/Mini_Rifter/`](projects/Mini_Rifter/) — Ultra-compact single pusher cruiser
  * [`projects/Rifter_3/`](projects/Rifter_3/) — Rifter Generation 3 long-range cruiser
  * [`projects/Sabre/`](projects/Sabre/) — High-speed twin-tractor plank
  * [`projects/Scimitar_3/`](projects/Scimitar_3/) — Swept flying wing
  * [`projects/Sica/`](projects/Sica/) — Flagship heavy cruiser with COB LED lighting
  * [`projects/Common/`](projects/Common/) — Shared canopy locks, DJI O3 mounts, SCM
* **Original Distribution Backups (`archives/`):**  
  The [`archives/`](archives/) directory preserves the pristine original `.zip` releases for all airframes.

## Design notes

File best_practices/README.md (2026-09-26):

# 🛠️ AeroBlades Fleet Best Practices & Engineering Guides





Welcome to the **AeroBlades Engineering Best Practices Suite**. While each aircraft project in [`projects/`](../projects/) contains its individual 3D models and CAD data, this directory serves as the **master knowledge base** for successfully manufacturing, outfitting, and flying 3D-printed FPV cruisers and hybrid VTOL platforms.

Whether you are printing your first **Mini Rifter**, assembling a high-speed twin **Sabre**, wiring a long-range **Sica**, or commissioning the quad-motor **Urumi**, these guides distill proven aerodynamic principles, mechanical material analysis, and electronics integration standards.

---

## 📚 Master Engineering Guides

| Guide | Core Topic | Key Questions Answered | Quick Link |
| :--- | :--- | :--- | :---: |
| **01. Material Selection & Filaments** | Material engineering, composites & thermodynamics | Should I use Aero ASA? Where is PLA+ mandatory? Why do active foaming filaments fail on high-speed wings? | [Read Guide](01_MATERIALS_AND_FILAMENT_SELECTION.md) |
| **02. 3D Printing & Slicing Setup** | Slicer optimization, tolerances & bed adhesion | How does the thin-wall gyroid truss system work? How do I account for carbon spar hole shrinkage? | [Read Guide](02_3D_PRINTING_AND_SLICER_SETUP.md) |
| **03. Electronics, Propulsion & Power** | Motors, ESCs, LiPo vs Li-ion batteries | What stator size and KV for pusher vs twin tractor? When should I use 21700 Li-ion cells vs high-C LiPos? | [Read Guide](03_ELECTRONICS_PROPULSION_AND_POWER.md) |
| **04. Avionics, FPV & RF Integration** | Flight controllers, INAV, GPS hygiene, FPV | How far must GPS be from DJI O3? How do I prevent compass magnetic interference from motor lines? | [Read Guide](04_AVIONICS_FPV_AND_RF_INTEGRATION.md) |
| **05. References & Authoritative Sources** | Industry benchmarks, citations & manufacturer TDS | What testing proves active-foaming strength reduction? What are Mooch's verified 21700 cell ratings? | [Read Guide](05_REFERENCES_AND_CITATIONS.md) |

---

## ⚡ The 5 Golden Rules of AeroBlades Aircraft

1. **Rigidity Outweighs Theoretical Lightness:**  
   A wing printed 20% lighter in weak foaming filament that flutters and twists in a dive will crash. A stiff wing printed in PLA+ or tough filament flies faster, cruises more efficiently, and withstands high G-forces.
2. **Never Print Motor Mounts or Locks in Foaming Material:**  
   Foaming filaments (LW-PLA, Aero ASA) suffer from low inter-layer tensile strength and creep under screw compression. Use solid **PETG**, **standard ABS/ASA**, or **solid PLA+** for high-stress retention.
3. **Separate High-Current Power from Sensitive RF Sensors:**  
   Keep motor and battery lines at least 50mm–80mm away from the GPS compass and radio receiver antennas. Digital FPV transmitters (DJI O3, Walksnail) must be ventilated and physically isolated from UHF/ELRS receivers.
4. **Always Test-Fit Carbon Spars Before Gluing:**  
   Slicer hole expansion, material shrinkage (1.0%–1.5% on ASA), and seam blobs inside spar channels can cause carbon tubes to jam. Ream channels gently with a 6.0mm or 8.0mm drill bit or round file before assembly.
5. **Center of Gravity (CG) is Non-Negotiable:**  
   A 3D-printed plane with a rearward CG is unrecoverable. Always balance your plane slightly nose-heavy on the marked molded CG dimples before every maiden flight.

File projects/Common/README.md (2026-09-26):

# 📦 Common Hardware & Universal Accessories





> This directory contains shared components, modular camera bays, and standardized retention mechanisms utilized across the entire **AeroBlades** cruiser fleet (**Mini Rifter**, **Rifter 3**, **Sabre**, **Scimitar 3**, **Sica**, and **Urumi**).

---

## 📸 Overview Asset

Common Hardware

---

## 🧰 Modular Components Catalog

```mermaid
flowchart TD
    ECO["<b>📦 Common Fleet Hardware Ecosystem</b>"]
    
    ECO --> LATCH["🔒 <b>01_Canopy_Spring_Locks/</b><br/>Tool-free snap latches (Locks 1 & 2)<br/><i>Fits all airframe canopies</i>"]
    ECO --> O3["📹 <b>02_DJI_O3_Mounts/</b><br/>Vibration cage & ventilated heatsink mount<br/><i>Protects DJI O3 camera & VTX</i>"]
    ECO --> SCM["🎥 <b>03_Standard_Camera_Mounts_SCM/</b><br/>Interchangeable camera blocks<br/><i>DJI O3, Walksnail, HDZero Micro</i>"]
    ECO --> FC["⚡ <b>04_Universal_FC_Plates_and_Hardware/</b><br/>20×20, 25.5×25.5, 30.5×30.5 plates<br/><i>M3 knurl brass insert adapters</i>"]

    LATCH -.-> PLANES["<b>Compatible Airframes:</b><br/>Mini Rifter • Rifter 3 • Sabre • Scimitar 3 • Sica • Urumi"]
    O3 -.-> PLANES
    SCM -.-> PLANES
    FC -.-> PLANES
```

### 1. 🔒 Canopy Spring Locks (`01_Canopy_Spring_Locks/`)
* **`Canopy spring Lock 1.3mf` & `2.3mf`**: Standardized tool-free snap-latch mechanism used across canopies on all airframes.
* **Print Settings**: 100% infill in durable PLA+ or PETG for spring flex resistance.

### 2. 📹 DJI O3 Air Unit Ecosystem (`02_DJI_O3_Mounts/`)
* **`DJI O3 cage 1.3mf` & `2.3mf`**: Vibration-dampened structural cage protecting the DJI O3 camera module.
* **`DJI O3 VTX mount.3mf`**: Secure ventilated bracket for mounting the DJI O3 air unit heatsink.

### 3. 🎥 Standard Camera Mount (SCM) (`03_Standard_Camera_Mounts_SCM/`)
* **`DJI O3 Cam mount.3mf`, `HDZero Micro Cam mount.3mf`, `Walksnail Cam mount.3mf`**: Interchangeable mounting blocks for modern HD digital FPV cameras.
* **`CAD_Source_Fusion/DJI O3 Camera.f3d`**: Parametric Fusion 360 source model for custom camera housing design.

### 4. ⚡ Universal Flight Controller Trays & Hardware (`04_Universal_FC_Plates_and_Hardware/`)
* **`FC plate 1.3mf`, `2.3mf`, `3.3mf`, `4 24x30.3mf`**: Universal mounting trays for 20x20mm, 25.5x25.5mm, and 30.5x30.5mm flight controllers and 4-in-1 ESCs.
* **`M3 knurl.3mf`**: Press-fit threaded knurl insert adapters for standard M3 standoffs.

---

## 📂 Directory Structure

```
Common/
├── README.md
├── 3D_Print_Files/
│   ├── 01_Canopy_Spring_Locks/               # Tool-free snap latches
│   ├── 02_DJI_O3_Mounts/                     # DJI O3 cage & VTX bracket
│   ├── 03_Standard_Camera_Mounts_SCM/        # DJI O3, HDZero, Walksnail mounts
│   └── 04_Universal_FC_Plates_and_Hardware/  # FC plates 1-4, M3 knurl
├── CAD_Source_Fusion/                        # Parametric Fusion 360 camera models
└── media/                                    # Overview diagram
```

[⬅️ Back to Unified Fleet Catalog](../../CATALOG.md)

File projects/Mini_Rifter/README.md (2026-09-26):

# 🛩️ Mini Rifter: Ultra-Compact FPV Cruiser






> **Mini Rifter** is a scaled-down, ultra-portable edition of the Rifter cruiser platform. It features an aerodynamically refined pusher configuration, high efficiency, and docile cruising capabilities on small battery packs.

---

## 📸 Aircraft Gallery

| Top View | Front View |
| :---: | :---: |
| Top | Front |
| **Side Profile** | **Disassembled Airframe & Parts** |
| Side | Parts |

---

## ⚡ Specifications & Engineering Data

| Parameter | Specification | Notes |
| :--- | :--- | :--- |
| **Airframe Configuration** | Conventional single-motor pusher cruiser | Clean laminar flow nose |
| **Total Printed Weight** | **314 g** | Standard PLA+ / LW-PLA setup |
| **Total Print Time** | **19 hours 18 minutes** | Bambu Lab P1P / P1S reference |
| **Carbon Spars Required** | **Front Spar:** 6.0 mm × 600 mm<br>**Rear Spar:** 6.0 mm × 260 mm | Hollow carbon fiber tubes |
| **Control Surfaces** | 2 Ailerons + V-tail / Stabs | Driven by sub-micro/9g servos |
| **Recommended Propulsion** | 1806 – 2204 brushless motor, 4"–5" prop | Efficient rear pusher mount |
| **Battery Compatibility** | 3S 18650 Li-ion pack or 3S/4S 1300–1500mAh LiPo | Fits forward battery bay |
| **FPV System Support** | Analog, Walksnail Avatar, DJI O3 Air Unit | Standard & External O3 mounts included |

```mermaid
graph TD
    subgraph FUSELAGE["Fuselage Structure (01_Fuselage/)"]
        F1["Fuselage 1 (Nose)"] --- F2["Fuselage 2 (Bulkhead)"]
        F2 --- F3["Fuselage 3 (Electronics Bay)"]
        F3 --- F4["Fuselage 4 (Rear Boom)"]
    end

    subgraph WINGS["Wing Assembly (02_Wings/)"]
        W1["Wing 1 & 2 (L/R)"] --- AIL["Ailerons (L/R)"]
        W1 --- WL["Wing Locks"]
    end

    subgraph TAIL["Tail & Propulsion (03_Tail_and_Stabs/)"]
        STAB["Wing Stabs (L/R)"]
        MOTOR["Pusher Motor Mount"]
    end

    F3 ===|Front Spar: 6.0mm × 600mm| W1
    F4 ===|Rear Spar: 6.0mm × 260mm| W1
    F4 --- TAIL
    F3 --- CANOPY["<b>05_Canopy/</b><br/>Canopy F & R + Locks"]
```

---

## 🖨️ 3D Printing Bill of Materials (ODS Data)

| Part Name | Category Folder | Profile | Infill % / Type | Print Time (P1P) | Weight (g) | Slicing Modifiers |
| :--- | :--- | :---: | :---: | :---: | :---: | :--- |
| **Fuselage 1** | `01_Fuselage/` | C | 0% | 00:21 | 7 | Nose section |
| **Fuselage 2** | `01_Fuselage/` | C | 100% Solid | 00:05 | 2 | Forward bulkhead |
| **Fuselage 3** | `01_Fuselage/` | A | 6% Gyroid | 02:42 | 35 | Electronics bay |
| **Fuselage 4** | `01_Fuselage/` | A | 6% Gyroid | 03:05 | 46 | Rear fuselage & boom |
| **F3F4 pins** | `01_Fuselage/` | C | 100% Solid | - | - | Alignment pins |
| **Wing L 1 / R 1** | `02_Wings/` | A | 4% Gyroid | 01:12 each | 24 each | 1 wall, 3 top/bottom |
| **Wing L 2 / R 2** | `02_Wings/` | A | 4% Gyroid | 03:19 each | 43 each | +Support required |
| **Wing Ailerons 1 & 2** | `02_Wings/` | A | 6% Gyroid | 00:27 each | 10 each | 15 bottom layers |
| **Wing locks L & R** | `02_Wings/` | C | 0% | 00:34 | 13 | 4 walls, +support |
| **Wing L & R Stabs** | `03_Tail_and_Stabs/` | B | 6% Gyroid | 00:25 each | 13 each | 2 bottom, 2 top |
| **Motor mount** | `03_Tail_and_Stabs/` | C | 100% Solid | 00:08 | 5 | Align flat to plate |
| **Battery plate** | `04_Internal_Plates/` | C | 10% Gyroid | 00:19 | 10 | 3 bottom, 3 top |
| **Hinges (TPU)** | `04_Internal_Plates/` | B | 100% Solid | 00:10 | 1 | Flexible 95A TPU |
| **Canopy F** | `05_Canopy/` | C LW | 10% Gyroid | 00:25 | 5 | Foaming PLA-LW (2 b/t, 4 walls) |
| **Canopy R** | `05_Canopy/` | C LW | 10% Gyroid | 00:29 | 6 | Foaming PLA-LW (2 b/t, 4 walls) |
| **Canopy locks** | `05_Canopy/` | C | 0% | 00:14 | 4 | - |
| **Total** | - | - | - | **19:18** | **314 g** | - |

---

## 📂 Project Directory Structure

```
Mini_Rifter/
├── README.md
├── Mini Rifter.ods
├── 3D_Print_Files/
│   ├── 01_Fuselage/           # Fuselage 1, 2, 3, 4, F3F4 pins
│   ├── 02_Wings/              # Wing L/R 1 & 2, Ailerons 1 & 2, Wing locks
│   ├── 03_Tail_and_Stabs/     # Wing L/R Stabs, Motor mount
│   ├── 04_Internal_Plates/    # Battery plate, TPU hinges
│   ├── 05_Canopy/             # Canopy F, Canopy R, Canopy locks
│   └── Extras/                # SCM nose, no-holes nose, wingtips, external DJI O3 pod
├── CAD_Source_STEP/           # 16 complete CAD STEP models
└── media/
    ├── aircraft_photos/       # High-res photos of assembled Mini Rifter
    └── slicer_placement/      # 9 slicer bed orientation photos
```

---

## 🎬 Video Flight Logs
* 🎥 [Rifter Mini Flight Demonstration](https://www.youtube.com/watch?v=fl-8yHl3snQ) by Olivier_C

[⬅️ Back to Unified Fleet Catalog](../../CATALOG.md)

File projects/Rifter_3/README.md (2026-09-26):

# 🛩️ Rifter 3: Full-Size High-Endurance FPV Cruiser






> **Rifter 3** is the mature, third-generation evolution of the Rifter single-motor pusher cruiser. Boasting a large high-aspect-ratio wing, dedicated fuselage bays, and modular carbon reinforcement, it delivers exceptional glide ratios and long-range cruising.

---

## 📸 Aircraft Gallery

| Top View | Front View |
| :---: | :---: |
| Top | Front |
| **Side Profile** | **Disassembled Airframe & Parts** |
| Side | Parts |

---

## ⚡ Specifications & Engineering Data

| Parameter | Specification | Notes |
| :--- | :--- | :--- |
| **Airframe Configuration** | Single-motor pusher cruiser with V-tail | High efficiency glider/cruiser |
| **Total Printed Weight** | **430 g** | Standard PLA+ / LW-PLA setup |
| **Total Print Time** | **31 hours 40 minutes** | Bambu Lab P1P / P1S reference |
| **Carbon Spars Required** | **Front Spar:** 8.0 mm × 800 mm<br>**Rear Spar:** 6.0 mm × 400 mm<br>**Fuselage Spars (optional):** 2x 6.0 mm × 135 mm | High rigidity carbon spars |
| **Control Surfaces** | 2 Wing Ailerons + V-Tail Stabs | Precision flight stability |
| **Recommended Propulsion** | 2207 – 2806.5 brushless motor, 6"–7" folding or fixed prop | Rear-mounted quiet pusher |
| **Battery Compatibility** | 4S 18650 / 21700 Li-ion packs (up to 4000–5000mAh) or 4S LiPo | Long range endurance |
| **FPV System Support** | Analog, Walksnail, DJI O3, GPS mast mount | SCM nose & dedicated GPS plate |

```mermaid
graph TD
    subgraph FUSELAGE["Fuselage Structure (01_Fuselage/)"]
        F1["Fuselage 1 (Nose / SCM)"] --- F2["Fuselage 2 (Bulkhead)"]
        F2 --- F3["Fuselage 3 (Main Cabin)"]
        F3 --- F4["Fuselage 4 (Mid Section)"]
        F4 --- F5["Fuselage 5 (Tail Cone)"]
    end

    subgraph WINGS["Wing Panels (02_Wings/)"]
        W["Wings 1–4 (L/R)"] --- AIL["Ailerons (L/R)"]
        W --- WL["Wing Locks"]
    end

    subgraph TAIL["V-Tail Assembly (03_Tail_and_Stabs/)"]
        VTAIL["V-Tail Stabilizers (L/R)"]
        MOTOR["Pusher Motor Mount (2806.5)"]
    end

    F3 ===|Main Spar: 8.0mm × 800mm| W
    F4 ===|Rear Spar: 6.0mm × 400mm| W
    F3 -.-|Optional Stiffeners: 2× 6×135mm| F4
    F5 --- TAIL
    F3 --- CANOPY["<b>05_Canopy/</b><br/>Canopy + Snap Lock"]
```

---

## 🖨️ 3D Printing Bill of Materials (ODS Data)

| Part Name | Category Folder | Profile | Infill % / Type | Print Time (P1P) | Weight (g) | Slicing Modifiers |
| :--- | :--- | :---: | :---: | :---: | :---: | :--- |
| **Fuselage 1** | `01_Fuselage/` | B | 0% | 00:38 | 17 | Nose camera bay |
| **Fuselage 2** | `01_Fuselage/` | B | 100% Solid | 00:10 | 4 | Forward bulkhead |
| **Fuselage 3** | `01_Fuselage/` | A | 4% Gyroid | 02:41 | 37 | Main electronics cabin |
| **Fuselage 4** | `01_Fuselage/` | A | 4% Gyroid | 02:50 | 42 | Rear fuselage section |
| **Fuselage 5** | `01_Fuselage/` | B | 0% | 00:25 | 6.5 | Tail boom cone |
| **Hatch** | `01_Fuselage/` | B | 10% Gyroid | 00:20 | 10 | 2 bottom, 2 top layers |
| **Wing L/R 1** | `02_Wings/` | A | 6% Gyroid | 00:34 each | 11 each | 1 wall, 3 top/bottom |
| **Wing L/R 2** | `02_Wings/` | A (PMLW) | 4% Gyroid | 02:33 each | 36 each | Pre-foamed LW / PLA+ |
| **Wing L/R 3** | `02_Wings/` | A (PMLW) | 4% Gyroid | 03:19 each | 47 each | Extended wing section |
| **Wing L/R 4** | `02_Wings/` | B (LW) | 6% Gyroid | 01:26 each | 20 each | Wingtip section |
| **Wing Ailerons L & R** | `02_Wings/` | A | 6% Gyroid | 01:48 each | 12 each | 12 bottom layers |
| **Wing locks L & R** | `02_Wings/` | B / D | 100% Solid | 00:18 | 8.5 | Glueless wing locking |
| **Stabs LR (V-tail)** | `03_Tail_and_Stabs/` | A (LW) | 7% Gyroid | 01:04 each | 14 each | Foaming PLA-LW |
| **Motor mount** | `03_Tail_and_Stabs/` | B / D | 100% Solid | 00:12 | 3.5 | Solid screw retention |
| **Battery plate** | `04_Internal_Plates/` | B | 10% Gyroid | 00:16 | 9 | - |
| **Canopy** | `05_Canopy/` | A | 4% Gyroid | 02:03 | 20 | Main top hatch |
| **Canopy lock** | `05_Canopy/` | D | 100% Solid | 00:10 | 4 | - |
| **Total** | - | - | - | **31:40** | **430 g** | - |

---

## 📂 Project Directory Structure

```
Rifter_3/
├── README.md
├── Rifter3.ods
├── 3D_Print_Files/
│   ├── 01_Fuselage/           # Fuselage 1-5, Hatch
│   ├── 02_Wings/              # Wings 1-4 (L/R), Ailerons (L/R), Wing locks
│   ├── 03_Tail_and_Stabs/     # V-tail Stabs, Motor mount
│   ├── 04_Internal_Plates/    # Battery plate
│   ├── 05_Canopy/             # Canopy, Canopy lock
│   └── Extras/                # SCM camera nose, GPS plate
├── CAD_Source_STEP/           # 14 complete CAD STEP models
└── media/
    ├── aircraft_photos/       # High-res photos of assembled Rifter 3
    └── slicer_placement/      # 13 slicer bed orientation photos
```

---

## 🎬 Video Flight Logs
* 🎥 [Rifter 3 Flight Test](https://www.youtube.com/watch?v=L3LojPVs68U) by Olivier_C
* 🎥 [Rifter 2 Historic Video](https://www.youtube.com/watch?v=LL8X9GLXXWU) by Olivier_C

[⬅️ Back to Unified Fleet Catalog](../../CATALOG.md)

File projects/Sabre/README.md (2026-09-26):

# 🗡️ Sabre: High-Speed Twin-Tractor FPV Plank






> **Sabre** is a fast, aggressive twin-tractor "plank" cruiser. With twin counter-rotating tractor motors mounted on wing nacelles and an un-swept plank wing layout, Sabre delivers blistering acceleration, locked-in pitch stability, and thrilling low-altitude carving.

---

## 📸 Aircraft Gallery

| Top View | Front View |
| :---: | :---: |
| Top | Front |
| **Side Profile** | **Disassembled Airframe & Parts** |
| Side | Parts |

---

## ⚡ Specifications & Engineering Data

| Parameter | Specification | Notes |
| :--- | :--- | :--- |
| **Airframe Configuration** | Twin-motor tractor plank with twin stabilizers | Fast forward cruiser |
| **Total Printed Weight** | **476 g** | Standard PLA+ setup |
| **Total Print Time** | **45 hours 41 minutes** | Bambu Lab reference |
| **Carbon Spars Required** | **Front Spar:** 6.0 mm × 680 mm<br>**Rear Spar:** 6.0 mm × 320 mm | Dual hollow carbon spars |
| **Control Surfaces** | 2 Wing Elevons / Ailerons | Servo bays embedded in wings |
| **Recommended Propulsion** | 2x 1404 – 1806 brushless motors, 4"–5" counter-rotating props | Differential thrust capable |
| **Battery Compatibility** | 4S 1500–2200mAh LiPo or 4S 18650 Li-ion pack | Ample central battery tray |
| **FPV System Support** | GoPro / RunCam, DJI O3, Walksnail, Analog | Dedicated GoPro & SCM nose options |

```mermaid
graph TD
    subgraph FUSELAGE["Fuselage Structure (01_Fuselage/)"]
        F1["Fuselage 1 (GoPro / SCM Nose)"] --- F2["Fuselage 2 (Firewall)"]
        F2 --- F3["Fuselage 3 (Payload Bay)"]
        F3 --- F4["Fuselage 4 (Aft Body)"]
    end

    subgraph WINGS["Plank Wing Assembly (02_Wings/)"]
        W["Wings 1–3 (L/R)"] --- ELEV["Elevons (L/R)"]
        W --- SERVO["Embedded Servo Bays"]
    end

    subgraph NACELLES["Twin Propulsion (03_Nacelles_and_Mounts/)"]
        N1["Left Nacelle (CW Motor)"]
        N2["Right Nacelle (CCW Motor)"]
        STAB["Twin Vertical Fins"]
    end

    F3 ===|Front Spar: 6.0mm × 680mm| W
    F4 ===|Rear Spar: 6.0mm × 320mm| W
    W --- N1
    W --- N2
    W --- STAB
    F3 --- CANOPY["<b>05_Canopy/</b><br/>Canopy + Lock"]
```

---

## 🖨️ 3D Printing Bill of Materials (ODS Data)

| Part Name | Category Folder | Profile | Print Time | Weight (g) | Slicing Modifiers |
| :--- | :--- | :---: | :---: | :---: | :--- |
| **Fuselage 1** | `01_Fuselage/` | B | 01:03 | 12 | Standard nose |
| **Fuselage 2** | `01_Fuselage/` | D | 00:44 | 5 | Forward firewall |
| **Fuselage 3** | `01_Fuselage/` | A | 05:04 | 59 | Main payload cabin |
| **Fuselage 4** | `01_Fuselage/` | A | 05:36 | 62 | Aft fuselage |
| **Hatch** | `01_Fuselage/` | B | 01:49 | 14 | 20% infill |
| **Wing L/R 1** | `02_Wings/` | A | 02:26 each | 27 each | 1 wall, 3 top, 0 infill |
| **Wing L/R 2** | `02_Wings/` | A | 03:26 each | 43 each | Wing center section |
| **Wing L/R 3** | `02_Wings/` | B | 01:32 each | 18 each | Wing outer tip |
| **Wing Ailerons L & R** | `02_Wings/` | A | 01:35 each | 9 each | 10 bottom layers + raft |
| **Wing locks L & R** | `02_Wings/` | D | 00:44 each | 4 each | Wing retention latches |
| **Wing servos L & R** | `02_Wings/` | D | 01:15 | 9 | Servo covers / mounts |
| **Nacelles L & R** | `03_Nacelles_and_Mounts/` | B | 00:59 each | 12 each | Twin motor nacelles |
| **Motor mount LR** | `03_Nacelles_and_Mounts/` | D | 00:56 each | 6 each | Solid 100% infill |
| **Stabs LR** | `03_Nacelles_and_Mounts/` | B | 01:13 each | 19 each | Align flat to build plate |
| **Battery plate** | `04_Internal_Plates/` | D | 01:28 | 11 | Align flat to build plate |
| **FC plate** | `04_Internal_Plates/` | D | 00:50 | 5 | Flight controller tray |
| **Hinges (TPU)** | `04_Internal_Plates/` | D | 00:20 | 2 | Flexible 95A TPU |
| **Canopy** | `05_Canopy/` | A | 01:40 | 20 | Main top canopy |
| **Canopy lock** | `05_Canopy/` | D | 00:10 | 1 | Quick-release latch |
| **Total** | - | - | **45:41** | **476 g** | - |

---

## 📂 Project Directory Structure

```
Sabre/
├── README.md
├── Sabre.ods
├── 3D_Print_Files/
│   ├── 01_Fuselage/           # Fuselage 1-4, Hatch
│   ├── 02_Wings/              # Wings 1-3 (L/R), Ailerons, Locks, Servos
│   ├── 03_Nacelles_and_Mounts/# Nacelles (L/R), Motor mounts, Stabs
│   ├── 04_Internal_Plates/    # Battery plate, FC plate, TPU hinges
│   ├── 05_Canopy/             # Canopy, Canopy lock
│   └── Extras/                # GoPro RC predator nose, SCM nose
├── CAD_Source_Fusion/         # 18 native parametric Fusion 360 (.f3d) models
└── media/
    ├── aircraft_photos/       # High-res photos of assembled Sabre
    └── slicer_placement/      # 21 slicer bed orientation photos
```

---

## 🎬 Video Flight Logs
* 🎥 [Sabre Flight Demonstration](https://www.youtube.com/watch?v=Vm1uSv3ZKd4) by Olivier_C

[⬅️ Back to Unified Fleet Catalog](../../CATALOG.md)

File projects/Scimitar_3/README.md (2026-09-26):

# 🦅 Scimitar 3: Swept-Wing FPV Flying Wing






> **Scimitar 3** is a high-performance 3D-printed swept flying wing powered by a central pusher motor. Engineered for clean laminar airflow, fast cruise speeds, and high aerobatic agility with zero fuselage drag.

---

## 📸 Aircraft Gallery

| Top View | Front View |
| :---: | :---: |
| Top | Front |
| **Side Profile** | **Disassembled Airframe & Parts** |
| Side | Parts |

---

## ⚡ Specifications & Engineering Data

| Parameter | Specification | Notes |
| :--- | :--- | :--- |
| **Airframe Configuration** | Swept flying wing with central pusher motor | Pure flying wing aerodynamics |
| **Total Printed Weight** | **438 g** | Standard PLA+ / LW-PLA setup |
| **Total Print Time** | **21 hours 02 minutes** | Bambu Lab P1P / P1S reference |
| **Carbon Spars Required** | **Main Wing Spar:** 8.0 mm × 750 mm<br>**Front Spars:** 2x 6.0 mm × 150 mm | Rigid swept spar structure |
| **Control Surfaces** | 2 Elevons | Pitch & roll combined mixer |
| **Recommended Propulsion** | 2207 – 2306 brushless motor, 5"–6" prop | High-thrust central pusher |
| **Battery Compatibility** | 4S 1500–2200mAh LiPo or 4S 18650 Li-ion pack | Central battery bay |
| **FPV System Support** | Analog, Walksnail Avatar, DJI O3 Air Unit | SCM camera mount & O3 compatibility |

```mermaid
graph TD
    subgraph FUSELAGE["Fuselage Body (01_Fuselage/)"]
        F1["Fuselage 1 (SCM Camera Nose)"] --- F2["Fuselage 2 (Payload Bay)"]
        F2 --- F3["Fuselage 3 (Motor Bulkhead)"]
    end

    subgraph WINGS["Swept Wing Panels (02_Wings/)"]
        W1["Wing 1 (Root)"] --- W2["Wing 2 (Mid)"]
        W2 --- W3["Wing 3 (Tip + Elevons)"]
        W3 --- TIPS["Extended Wingtips (+25mm)"]
    end

    subgraph MOTOR["Propulsion (03_Motor_Mount/)"]
        MOUNT["4mm Motor Mount (2207–2306)"]
    end

    F2 ===|Main Spar: 8.0mm × 750mm| W2
    F2 ===|Front Spars: 2× 6.0mm × 150mm| W1
    F3 --- MOUNT
    F2 --- CANOPY["<b>05_Canopy/</b><br/>Canopy Front & Rear + Locks"]
```

---

## 🖨️ 3D Printing Bill of Materials (ODS Data)

| Part Name | Category Folder | Profile | Infill % / Type | Print Time (P1P) | Weight (g) | Slicing Modifiers |
| :--- | :--- | :---: | :---: | :---: | :---: | :--- |
| **Fuselage 1** | `01_Fuselage/` | B | 0% | 00:44 | 19 | Standard nose |
| **Fuselage 1 SCM** | `01_Fuselage/` | B | 0% | 00:44 | 19 | Camera nose bay |
| **Fuselage 2** | `01_Fuselage/` | A | 4% Gyroid | 03:06 | 73 | Center payload bay |
| **Fuselage 3** | `01_Fuselage/` | A | 4% Gyroid | 03:09 | 80 | Motor mount bulkhead |
| **Wing L/R 1** | `02_Wings/` | A | 4% Gyroid | 00:49 each | 20 each | 1 wall, 3 top/bottom |
| **Wing L/R 2** | `02_Wings/` | A | 5% Gyroid | 02:59 each | 53 each | +Support required |
| **Wing L/R 3** | `02_Wings/` | A | 5% Gyroid | 00:54 each | 21 each | Wingtip section |
| **Wing Ailerons / Elevons**| `02_Wings/` | A | 6% Gyroid | 01:38 | 21 | 12 bottom layers |
| **Wing Locks** | `02_Wings/` | C | 100% Solid | 00:35 | 15 | 5 walls |
| **Motor mount 4mm** | `03_Motor_Mount/` | C | 100% Solid | 00:10 | 3 | Solid retention |
| **Battery plate** | `04_Internal_Plates/` | C | 10% Gyroid | 00:40 | 18 | 3 bottom, 3 top layers |
| **FC plate** | `04_Internal_Plates/` | C | 10% Gyroid | - | - | Stacking tray |
| **Hinges (TPU)** | `04_Internal_Plates/` | B | 100% Solid | 00:10 | 1 | Flexible 95A TPU |
| **Canopy F+R** | `05_Canopy/` | C LW | 10% Gyroid | 01:12 | 16 | Foaming LW-PLA (4 walls, 2 b/t) |
| **Canopy locks** | `05_Canopy/` | C | 0% | 00:14 | 4 | - |
| **Total** | - | - | - | **21:02** | **438 g** | - |

---

## 📂 Project Directory Structure

```
Scimitar_3/
├── README.md
├── Scimitar3.ods
├── 3D_Print_Files/
│   ├── 01_Fuselage/           # Fuselage 1, 1 SCM, 2, 3
│   ├── 02_Wings/              # Wings 1-3 (L/R), Ailerons, Wing locks
│   ├── 03_Motor_Mount/        # Motor mount 4mm
│   ├── 04_Internal_Plates/    # Battery plate, FC plate, TPU hinges
│   ├── 05_Canopy/             # Canopy F & R, Canopy locks
│   └── Extras/                # Extended wingtips (+25mm), centering pin, text canopy
├── CAD_Source_STEP/           # 10 complete CAD STEP models
└── media/
    ├── aircraft_photos/       # High-res photos of assembled Scimitar 3
    └── slicer_placement/      # 11 slicer bed orientation photos
```

---

## 🎬 Video Flight Logs
* 🎥 [Scimitar: 3D-Printed Flying Wing](https://www.youtube.com/watch?v=LZn1OF9eK5k) by Olivier_C

[⬅️ Back to Unified Fleet Catalog](../../CATALOG.md)

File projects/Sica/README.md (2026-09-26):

# ⚔️ Sica: Long-Range Twin-Tractor FPV Cruiser






> **Sica** is the flagship heavy long-range cruiser of the fleet. Featuring twin forward tractor motors, a generous fuselage payload cabin, twin vertical stabilizers, and full night-flight COB LED internal channels, Sica is the ultimate endurance platform.

---

## 📸 Aircraft Gallery

| Top View | Front View |
| :---: | :---: |
| Top | Front |
| **Side Profile** | **Disassembled Airframe & Parts** |
| Side | Parts |

---

## ⚡ Specifications & Engineering Data

| Parameter | Specification | Notes |
| :--- | :--- | :--- |
| **Airframe Configuration** | Twin-motor tractor cruiser with twin rudders & elevator | Heavy payload cruiser |
| **Total Printed Weight** | **746 g** | Standard PLA+ setup |
| **Total Print Time** | **39 hours 59 minutes** | Bambu Lab P1P / P1S reference |
| **Carbon Spars Required** | **Front Wing Spar:** 8.0 mm × 1000 mm (can be cut to 800 mm)<br>**Rear Wing Spar:** 6.0 mm × 700 mm<br>**Tail Stabilizer Spars (2x):** 8.0 mm × 330 mm | High rigidity heavy airframe |
| **Control Surfaces** | 2 Ailerons, 2 Vertical Rudders, 1 Horizontal Elevator | Full 4-axis flight authority |
| **Recommended Propulsion** | 2x 2207 – 2806.5 brushless motors, 6"–7" props | Massive endurance & speed envelope |
| **Battery Compatibility** | 4S 21700 4000–8000mAh Li-ion pack or large 4S LiPo | Massive central battery bay |
| **FPV & Payload Support** | DJI O3 1-axis pan/tilt dome, HEQ G-Port gimbal, COB LEDs | Dedicated gimbal & O3 dome noses |

```mermaid
graph TD
    subgraph FUSELAGE["Heavy Fuselage (01_Fuselage/)"]
        F1["Fuselage 1 (Gimbal / O3 Dome Nose)"] --- F2["Fuselage 2 (Bulkhead)"]
        F2 --- F3["Fuselage 3 (Avionics Bay)"]
        F3 --- F4["Fuselage 4 (Battery Bay)"]
        F4 --- F5["Fuselage 5 (Tail Sockets)"]
    end

    subgraph WINGS["4-Panel Wing Assembly (02_Wings/)"]
        W["Wings 1–4 (L/R)"] --- AIL["Dual Ailerons (L/R)"]
        W --- NAC["Twin Nacelles (CW+CCW Motors)"]
    end

    subgraph TAIL["Twin Rudder & Elevator (03_Tail_and_Nacelles/)"]
        STAB["Twin Vertical Stabs 1 & 2"] --- RUD["Twin Rudders"]
        STAB --- ELEV["Horizontal Elevator"]
    end

    F3 ===|Front Spar: 8.0mm × 1000mm| W
    F4 ===|Rear Spar: 6.0mm × 700mm| W
    F5 ===|Tail Spars: 2× 8.0mm × 330mm| STAB
    F3 --- CANOPY["<b>05_Canopy/</b><br/>Front & Rear Canopies + Handles"]
```

---

## 🖨️ 3D Printing Bill of Materials (ODS Data)

| Part Name | Category Folder | Profile | Infill % / Type | Print Time (P1P) | Weight (g) | Slicing Modifiers |
| :--- | :--- | :---: | :---: | :---: | :---: | :--- |
| **Fuselage 1** | `01_Fuselage/` | C | 0% | 00:38 | 14 | Nose bay |
| **Fuselage 2** | `01_Fuselage/` | C | 100% Solid | 00:09 | 4 | Forward bulkhead |
| **Fuselage 3** | `01_Fuselage/` | A | 6% Gyroid | 02:14 | 31 | Avionics bay |
| **Fuselage 4** | `01_Fuselage/` | A | 6% Gyroid | 02:25 | 40 | Battery bay |
| **Fuselage 5** | `01_Fuselage/` | A | 6% Gyroid | 02:17 | 26 | Rear fuselage & tail mount |
| **Wing L/R 1** | `02_Wings/` | A | 3% Gyroid | 02:09 / 02:35 | 49 / 57 | +Support required |
| **Wing L/R 2** | `02_Wings/` | A | 3% Gyroid | 02:09 / 02:35 | 49 / 57 | +Support required |
| **Wing L/R 3** | `02_Wings/` | A | 3% Gyroid | 03:29 each | 57 each | Wing middle section |
| **Wing L/R 4** | `02_Wings/` | A | 6% Gyroid | 00:50 each | 12 each | Wingtip section |
| **Wing Ailerons 1 & 2** | `02_Wings/` | A | 6% Gyroid | 01:51 | 23 | 13 bottom layers |
| **Wing locks L & R** | `02_Wings/` | C | 10% Gyroid | 00:41 | 26 | 5 walls |
| **Nacelles L & R** | `03_Tail_and_Nacelles/` | C | 6% Gyroid | 00:49 each | 33 each | Twin tractor motor nacelles |
| **Motor mounts L & R** | `03_Tail_and_Nacelles/` | C | 100% Solid | 01:07 | 34 | Solid screw retention |
| **Stab 1** | `03_Tail_and_Nacelles/` | A | 3% Gyroid | 01:13 | 22 | +Support required |
| **Stab 2 L & R** | `03_Tail_and_Nacelles/` | B | 3% Gyroid | 00:53 | 33 | +Support required |
| **Rudders L & R** | `03_Tail_and_Nacelles/` | A | 6% Gyroid | 01:45 each | 14 each | Twin vertical rudders |
| **Elevator L & R** | `03_Tail_and_Nacelles/` | A | 5% Gyroid | 01:58 | 15 | 13 bottom layers |
| **Battery plate** | `04_Internal_Plates/` | C | 10% Gyroid | 00:21 | 11 | 3 bottom, 3 top layers |
| **Hinges (TPU)** | `04_Internal_Plates/` | B | 100% Solid | 00:10 | 1 | Flexible 95A TPU |
| **Canopy Front** | `05_Canopy/` | C | 6% Gyroid | 00:25 | 13 | 2 bot, 2 top, 5 walls |
| **Canopy Rear** | `05_Canopy/` | C | 6% Gyroid | 00:18 | 8 | 2 bot, 2 top, 5 walls |
| **Canopy handle** | `05_Canopy/` | B | 100% Solid | 00:05 | 1 | Quantity: 2 |
| **Total** | - | - | - | **39:59** | **746 g** | - |

---

## 📂 Project Directory Structure

```
Sica/
├── README.md
├── Sica.ods
├── 3D_Print_Files/
│   ├── 01_Fuselage/           # Fuselage 1-5
│   ├── 02_Wings/              # Wings 1-4 (L/R), Ailerons 1 & 2 (L/R), Wing locks
│   ├── 03_Tail_and_Nacelles/  # Nacelles, Motor mounts, Stabs 1 & 2, Rudders, Elevators
│   ├── 04_Internal_Plates/    # Battery plate, TPU hinges
│   ├── 05_Canopy/             # Canopy Front & Rear, Canopy handles
│   └── Extras/                # HEQ G-Port gimbal, O3 Pan/Tilt dome, COB LED suites
├── CAD_Source_STEP/           # 21 individual STEP files + full Sica v243 assembly STEP
└── media/
    ├── aircraft_photos/       # High-res photos of assembled Sica
    └── slicer_placement/      # 20 slicer bed orientation photos
```

---

## 🎬 Video Flight Logs
* 🎥 [New Twin Tractor (Sica Introduction)](https://www.youtube.com/watch?v=HihsU5iFMYI) by Olivier_C
* 🎥 [Neon Nights (Sica Full COB LED Night Flight)](https://www.youtube.com/watch?v=hPF_NwX6mRE) by Olivier_C

[⬅️ Back to Unified Fleet Catalog](../../CATALOG.md)

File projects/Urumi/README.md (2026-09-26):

# 🛸 Urumi: Experimental Hybrid VTOL / Quadplane








> **Urumi** is an experimental hybrid VTOL aircraft combining vertical helicopter hovering (quadcopter mode) with high-speed wing-borne forward flight (aeroplane mode). It features an X-wing layout with four 22° dihedral wings, four brushless motors, a tilting servo camera, and **no moving control surfaces**—steering is achieved entirely via differential motor thrust.

---

## 📸 Aircraft Gallery

| Top View | Front View |
| :---: | :---: |
| Urumi Top | Urumi Front |
| **Side Profile** | **Disassembled Airframe & Removable Wings** |
| Urumi Side | Urumi Parts |

---

## ⚡ Specifications & Flight Characteristics

| Parameter | Specification | Notes |
| :--- | :--- | :--- |
| **Airframe Weight (Plastic)** | **565 g – 571 g** | Printed mostly in PLA+ / PLA Basic |
| **Dry Weight (with FPV Gear)**| **1035 g** | Without flight battery |
| **All-Up-Weight (AUW)** | **~1215 g** | Including 4S 1500mAh 100C LiPo (~180g) |
| **Wing Dimensions** | 4 wings @ 20 × 20 cm | Equivalent to an 80 × 20 cm single wing area |
| **Wing Dihedral Angle** | **22°** | Optimised for 7" prop clearance while maintaining vertical hover thrust |
| **Transition Airspeed** | **70 – 80 km/h** | Speed at which wings produce full flight lift |
| **Control Surfaces** | **None** | Differential thrust provides pitch, roll, and yaw control |
| **Camera Mechanism** | 9g Servo Tilting Mount | 90° (hover) → 45° (transition) → 0° (forward cruise) |
| **Carbon Spars Required** | **4x** 6.0 mm × 284 mm | Forms rigid central X-frame |

```mermaid
graph TD
    subgraph FUSELAGE["Fuselage Core (01_Fuselage/)"]
        F1["Fuselage 1 (Tilting Camera Nose)"] --- F2["Fuselage 2 (Battery Bay)"]
        F2 --- F3["Fuselage 3 (Central X-Frame Hub)"]
        F3 --- F4["Fuselage 4 (Rear Fin & FC Bay)"]
    end

    subgraph XFRAME["Central X-Frame Carbon Structure"]
        SPAR["4× 6.0mm × 284mm Carbon Tubes"]
    end

    subgraph QUAD_WINGS["Quad Dihedral Wings (02_Wings/)"]
        W1["Wing 1 (Top Left, 22°)"]
        W2["Wing 2 (Top Right, 22°)"]
        W3["Wing 3 (Bottom Left, 22°)"]
        W4["Wing 4 (Bottom Right, 22°)"]
    end

    subgraph PROPULSION["Nacelles & Mounts (03_Nacelles_and_Mounts/)"]
        N["Nacelles 1–4"] --- M["Motor Mounts 1–4 (Solid)"]
        N --- P["Landing Pads 1–4"]
    end

    F3 === XFRAME
    XFRAME === QUAD_WINGS
    QUAD_WINGS === PROPULSION
    F2 --- CANOPY["<b>05_Canopy/</b><br/>Canopies 1 & 2 + Locks"]
```

---

## 🖨️ 3D Printing Bill of Materials (ODS Data)

| Part Name | Category Folder | Profile | Infill % / Type | Print Time (P1P) | Weight (g) | Slicing Modifiers |
| :--- | :--- | :---: | :---: | :---: | :---: | :--- |
| **Fuselage 1** | `01_Fuselage/` | B | 0% | 00:47 | 18 | Tilting camera bay |
| **Fuselage 2** | `01_Fuselage/` | A | 4% Gyroid | 03:02 | 58 | 8 top layers |
| **Fuselage 3** | `01_Fuselage/` | C | 0% | 01:01 | 35 | Central carbon spar junction |
| **Fuselage 4** | `01_Fuselage/` | A | 5% Gyroid | 02:55 | 53 | Aft fuselage |
| **Wings 1, 2, 3, 4** | `02_Wings/` | A | 3% Gyroid | 03:10 each | 58 each | 1+2 identical, 3+4 identical |
| **Nacelles 1+2+3+4** | `03_Nacelles_and_Mounts/` | B | 0% | 02:04 | 60 | 1+2 identical, 3+4 identical (+support) |
| **Motor mounts 1-4** | `03_Nacelles_and_Mounts/` | C | 100% Solid | 01:09 | 48 | Solid screw retention |
| **Pads 1+2+3+4** | `03_Nacelles_and_Mounts/` | C | 0% | 00:58 | 29 | Landing pads (all 4 different) |
| **Battery plate** | `04_Internal_Plates/` | A | 8% Gyroid | 00:19 | 11 | 3 walls |
| **FC plate** | `04_Internal_Plates/` | A | 8% Gyroid | 00:15 | 5 | 3 walls |
| **Servo plate** | `04_Internal_Plates/` | A | 8% Gyroid | 00:10 | 5 | 3 walls |
| **Camera mount** | `04_Internal_Plates/` | C | 0% | 00:36 | 8 | Tilting 9g servo mount (+support) |
| **Canopy 1** | `05_Canopy/` | C LW | 10% Gyroid | 00:32 | 8 | Foaming LW-PLA (4 walls, 2 b/t) |
| **Canopy 2** | `05_Canopy/` | C LW | 10% Gyroid | 00:24 | 5 | Foaming LW-PLA (4 walls, 2 b/t) |
| **Canopy locks** | `05_Canopy/` | C | 0% | 00:14 | 4 | Canopy retention latches |
| **Total** | - | - | - | **26:30** | **571 g** | - |

---

## 📂 Project Directory Structure

```
Urumi/
├── README.md                                  # Aircraft documentation (this file)
├── Urumi.ods                                  # Original CAD spreadsheet archive
│
├── 📂 3D_Print_Files/                         # 3MF models organized by assembly stage
│   ├── 01_Fuselage/                           # Fuselage 1, 2, 3, 4
│   ├── 02_Wings/                              # Wing 1-2, Wing 3-4 (with mirroring)
│   ├── 03_Nacelles_and_Mounts/                # Nacelles 1-4, Motor mounts, Landing pads 1-4
│   ├── 04_Internal_Plates/                    # Battery plate, FC plate, Servo plate, Camera mount
│   ├── 05_Canopy/                             # Canopy 1, Canopy 2, Canopy locks
│   └── Extras/                                # Tighter motor mounts, Wing roots 1-4
│
├── 📂 CAD_Source_STEP/                        # 19 raw STEP files for CAD modifications
├── 📂 docs/                                   # Complete 6-document build & flight manual suite
│   ├── 01_HARDWARE_ELECTRONICS.md
│   ├── 02_HARDWARE_PARTS_AND_MECHANICAL.md
│   ├── 03_PRINT_GUIDE_AND_PROFILES.md
│   ├── 04_ASSEMBLY_AND_WIRING.md
│   ├── 05_INAV_FLIGHT_MANUAL.md
│   └── 06_DESIGNER_FLIGHT_LOGS_AND_VIDEO_TRANSCRIPTS.md
│
└── 📂 media/
    ├── aircraft_photos/                       # Assembled aircraft photography
    └── slicer_placement/                      # 11 bed orientation photos
```

---

## 📚 Complete In-Depth Documentation Suite

All detailed manuals, wiring schematics, and tuning guides are located in [`docs/`](docs/):

1. ⚡ **[Hardware Electronics & Configuration Software](docs/01_HARDWARE_ELECTRONICS.md)**
2. 🔩 **[Hardware Parts, Mechanical Structure & Materials](docs/02_HARDWARE_PARTS_AND_MECHANICAL.md)**
3. 🖨️ **[3D Printing Guide & Master Slicer Profiles](docs/03_PRINT_GUIDE_AND_PROFILES.md)**
4. 🛠️ **[Airframe Assembly & Wiring Guide](docs/04_ASSEMBLY_AND_WIRING.md)**
5. ✈️ **[INAV Hybrid VTOL Flight Manual](docs/05_INAV_FLIGHT_MANUAL.md)**
6. 🎬 **[Designer Flight Logs, Video Transcripts & History](docs/06_DESIGNER_FLIGHT_LOGS_AND_VIDEO_TRANSCRIPTS.md)**

---

## 🎬 Video Flight Logs
* 🎥 [Part 1 (Conception & Transition)](https://www.youtube.com/watch?v=R3-GTveqTRI) by Olivier_C
* 🎥 [Part 2 (Crash Investigation & Redesign)](https://www.youtube.com/watch?v=sHy94xdoC1A) by Olivier_C
* 🎥 [Part 3 (Final Flights & Wind Limits)](https://www.youtube.com/watch?v=J87EU8D0PFA) by Olivier_C

[⬅️ Back to Unified Fleet Catalog](../../CATALOG.md)

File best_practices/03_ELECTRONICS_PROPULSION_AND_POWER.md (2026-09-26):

# ⚡ Guide 03: Powertrain Engineering Guide (Motor, Propeller, ESC & Battery)




Designing the propulsion and electrical power system for a 3D-printed aircraft is an engineering chain: **Weight $\rightarrow$ Required Thrust $\rightarrow$ Propeller $\rightarrow$ Motor (Stator & KV) $\rightarrow$ ESC $\rightarrow$ Battery**.

Because 3D-printed airframes have poor thermal dissipation compared to open carbon quadcopter frames, selecting under-sized motors or under-rated ESCs will cause thermal failure inside plastic bays. Conversely, over-sizing components adds unnecessary dead weight, increasing stall speed and ruining glide performance.

This guide provides the complete mathematical framework, component selection criteria, and turnkey procurement recipes for the **AeroBlades** fleet.

---

## 1. The 5-Step Powertrain Sizing Algorithm

```mermaid
flowchart TD
    Step1["Step 1: Estimate All-Up-Weight (AUW)<br/><i>(Airframe + Spars + Electronics + Battery)</i>"]
    Step2["Step 2: Determine Required Thrust & T:W Ratio<br/><i>(Cruising: 0.3:1 | Hand Launch: 1.0:1 | VTOL: 2.2:1)</i>"]
    Step3["Step 3: Select Propeller<br/><i>(Diameter for Static Thrust | Pitch for Top Speed)</i>"]
    Step4["Step 4: Select Motor<br/><i>(Stator Volume for Torque | KV matched to Voltage)</i>"]
    Step5["Step 5: Size ESC & Battery<br/><i>(ESC +30% Headroom | High-C LiPo vs 21700 Li-ion)</i>"]

    Step1 --> Step2
    Step2 --> Step3
    Step3 --> Step4
    Step4 --> Step5
```

### Step 1: Calculate Target All-Up-Weight (AUW)
$$\text{AUW} = \text{Plastic Print Weight} + \text{Carbon Spars} + \text{Electronics (FC, Servos, VTX, Cam, Rx)} + \text{Battery}$$
* *Plastic Print Weights (from master tables)*: Mini Rifter (314g), Rifter 3 (430g), Sabre (476g), Scimitar 3 (438g), Sica (746g), Urumi (571g).
* *Typical Fixed Electronics Payload*: ~120g – 180g (FC + 2–4 servos + DJI O3 + ELRS receiver + wiring).
* *Battery Weight*:
  * 4S 1500mAh 100C LiPo: ~180g – 200g
  * 4S1P 18650 Li-ion pack: ~205g
  * 4S1P 21700 Li-ion pack: ~295g – 310g

---

### Step 2: Determine Required Thrust & Thrust-to-Weight (T:W) Ratio
Unlike multirotors (which require $T:W > 1.0$ simply to lift off the ground), a fixed-wing aircraft generates lift aerodynamically from its wings:
* **Level Cruise**: Requires only **$0.2:1$ to $0.3:1$ thrust-to-weight** ratio.
* **Hand Launch & Climb-Out**: Requires at least **$0.8:1$ to $1.2:1$**.
* **High-Speed Carving & Vertical Climbs (Sabre)**: Target **$2.0:1$ to $3.0+:1$**.
* **Hybrid VTOL Hover (Urumi)**: Requires **$2.0:1$ to $2.5:1$ minimum** total thrust across all 4 motors to maintain stable hover in wind and recover smoothly from transitions.

---

### Step 3: Select Propeller (Diameter vs. Pitch)

Propellers are defined by two numbers: **Diameter $\times$ Pitch** (e.g., $7 \times 4$ inches).

#### A. Diameter (Disc Area = Static Thrust & Launch Punch)
$$\text{Static Thrust} \propto D^3 \times P \times \text{RPM}^2$$
* Larger diameter moves a larger mass of air at lower velocity, producing **higher efficiency (thrust-per-watt)** and easier hand launches.
* *Constraint*: Physical airframe clearance (fuselage boom clearance on pushers, ground clearance on landing).

#### B. Pitch (Pitch Speed = Top Airspeed)
Pitch is the theoretical forward distance the propeller advances in one revolution.
$$\text{Pitch Speed (km/h)} = \text{RPM} \times \text{Pitch (inches)} \times 0.001524$$

* **Rule of Thumb**:
  * Pitch speed must be at least **$1.5\times$ to $2.0\times$ the aircraft stall speed** ($V_{\text{stall}} \approx 30\text{--}40\text{ km/h}$).
  * For efficient cruising: Use moderate pitch ($7\times4$ or $6\times4$).
  * For high-speed planks (Sabre): Use high pitch-to-diameter ratio ($5\times5$ or $4\times4.5$).

#### C. Number of Blades (2-Blade vs. 3-Blade)
* **2-Blade Propellers (Recommended for Cruisers)**: Highest aerodynamic efficiency ($\eta \approx 75\%-82\%$). Less blade interference drag.
* **3-Blade Propellers**: Used when diameter is constrained by fuselage geometry (e.g. Mini Rifter or Scimitar) to increase disc area within a compact diameter. Produces smoother video with lower vibration harmonics.

---

### Step 4: Motor Sizing (Stator Dimensions & KV)

#### A. Stator Sizing (Torque Capacity)
Brushless motor size is defined by stator width and height in millimeters (e.g., **2207** = 22mm diameter, 7mm height):
* **1404 – 1806**: For light twin tractors (Sabre) or ultra-compact cruisers (Mini Rifter).
* **2207 – 2306**: Standard FPV motor size. Excellent power-to-weight, high availability. Ideal for Mini Rifter, Scimitar 3, Urumi.
* **2806.5 – 2807**: Heavy long-range motor. High iron volume, massive torque to swing large 7" props at low RPM without overheating. Ideal for Rifter 3, Sica, Urumi.

#### B. Motor KV Calculation
$\text{KV}$ is the theoretical RPM per Volt under zero load:
$$\text{Loaded RPM} \approx \text{Battery Nominal Voltage} \times \text{Motor KV} \times 0.80$$

| Battery Voltage | Target Propeller Size | Optimal KV Range | Typical Application |
| :---: | :---: | :---: | :--- |
| **3S (11.1V)** | 4" – 5" | **2300 – 2700 KV** | Mini Rifter (Park flyer) |
| **4S (14.8V)** | 4" – 5" | **2400 – 2800 KV** | Sabre (High-speed twin) |
| **4S (14.8V)** | 6" – 7" | **1700 – 1950 KV** | Rifter 3, Sica, Urumi (Standard efficiency) |
| **6S (22.2V)** | 6" – 7" | **1200 – 1400 KV** | Sica (Heavy long-range cruise) |

> 💡 **Why 4S/6S is More Efficient than 3S:**  
> Power is $P = V \times I$. To deliver 300 Watts on 3S requires ~27 Amps. On 6S, it requires only ~13.5 Amps. Since resistive heat loss in motor windings and wires is $P_{\text{loss}} = I^2 R$, halving the current reduces resistive heat loss by **75%**!

---

### Step 5: ESC & Battery Selection

#### A. ESC Amperage Sizing
* **The 30% Headroom Rule**: Inside 3D-printed plastic fuselages, cooling airflow is limited. If static full throttle draws 25A on the bench, use a **35A to 45A ESC**.
* **Firmware**: Use **AM32** or **BLHeli_32** with bi-directional DShot. Set PWM frequency to **24kHz or 48kHz** for smooth cruise and cooler running.
* **Low-ESR Capacitor**: Solder a 35V/50V 470µF–1000µF Low-ESR capacitor (Panasonic FR or Rubycon ZLH) directly at the ESC battery pads to suppress back-EMF spikes.

#### B. Battery Chemistry Decision Tree: LiPo vs. Li-ion

```mermaid
flowchart TD
    Q1{"Does the aircraft require > 30A burst<br/>or vertical hover?"}
    
    Q1 -- "YES" --> LIPO["<b>High-C LiPo (100C - 150C)</b><br/>• Urumi (VTOL hover: 70A-90A)<br/>• Sabre (Twin high-speed carving)"]
    
    Q1 -- "NO" --> Q2{"Is flight endurance > 30 min<br/>the primary goal?"}
    
    Q2 -- "YES" --> LIION21700["<b>21700 Li-ion Pack (Molicel P45B / P42A)</b><br/>• Rifter 3 (50-70 min cruise)<br/>• Sica (60-90 min heavy cruise)"]
    
    Q2 -- "NO" --> LIION18650["<b>18650 Li-ion Pack (Sony VTC6 / Samsung 30Q)</b><br/>• Mini Rifter (35-45 min park flyer)<br/>• Scimitar 3 (Compact wing)"]
```

---

## 2. Complete Turnkey Powertrain Recipes by Airframe

Here are flight-tested, off-the-shelf component combinations for each aircraft in the fleet:

### 1. 🛩️ Mini Rifter (Ultra-Compact Cruiser)
* **Goal**: Ultra-quiet, long endurance park flyer.
* **Propulsion Layout**: Single rear pusher.
* **Recommended Motor**: EMAX ECO II 2204 (1900KV on 4S) or 1806 (2300KV on 3S).
* **Propeller**: Gemfan 5126 2-blade or HQProp 5x3x3 3-blade.
* **ESC**: 25A – 30A BLHeli_S / AM32 slim wing ESC.
* **Battery**:
  * *Endurance Setup*: 3S1P or 4S1P 18650 Li-ion (Sony VTC6 3000mAh, ~205g) $\rightarrow$ **35–45 min flight time**.
  * *Lightweight Setup*: 3S 1300mAh 60C LiPo (~120g) $\rightarrow$ **20 min flight time**.
* **Cruising Current**: ~4.5A – 6A at 50 km/h.

---

### 2. 🛩️ Rifter 3 (High-Endurance V-Tail Cruiser)
* **Goal**: 100km+ range, high aerodynamic glide ratio.
* **Propulsion Layout**: Single rear pusher.
* **Recommended Motor**: BrotherHobby Avenger 2806.5 (1700KV) or T-Motor F90 2806.5 (1950KV).
* **Propeller**: APC 7x4E Thin Electric or Gemfan Flash 7040 2-blade.
* **ESC**: 40A – 50A AM32 / BLHeli_32 with heatsink.
* **Battery**: 4S1P 21700 Molicel P45B (4500mAh, ~305g) $\rightarrow$ **50–70 min flight time**.
* **Cruising Current**: ~3.8A – 5.2A at 60 km/h.

---

### 3. 🗡️ Sabre (High-Speed Twin-Tractor Plank)
* **Goal**: Blistering acceleration, 120+ km/h top speed, locked-in pitch.
* **Propulsion Layout**: Twin forward tractors (Counter-Rotating: Left CW, Right CCW).
* **Recommended Motors**: 2× T-Motor F1507 (2700KV) or 2× Flywoo 1404 (2750KV).
* **Propellers**: 2× HQProp T5x3 or Gemfan 4024 (1× CW, 1× CCW).
* **ESC**: 2× 25A–35A individual ESCs or a single 4-in-1 35A mini stack.
* **Battery**: 4S 1500mAh – 2200mAh 100C LiPo (e.g., Tattu R-Line 4S 1500mAh, ~185g).
* **Cruising Current**: ~7A – 9A total; Full Throttle: ~35A total.

---

### 4. 🦅 Scimitar 3 (Swept Flying Wing)
* **Goal**: Aerobatic agility, carving turns, high climb rate.
* **Propulsion Layout**: Single central pusher.
* **Recommended Motor**: T-Motor Velox V3 2207 (1950KV on 4S) or 2306 (2400KV on 4S).
* **Propeller**: Gemfan Hurricane 51466 Tri-blade or 6042 2-blade.
* **ESC**: 35A – 45A BLHeli_32 / AM32.
* **Battery**: 4S 1800mAh 100C LiPo or 4S1P 18650 Li-ion pack.
* **Cruising Current**: ~5A – 7A at 65 km/h.

---

### 5. ⚔️ Sica (Heavy Flagship Twin Cruiser)
* **Goal**: Maximum payload capacity, twin-camera FPV, night COB LED flights.
* **Propulsion Layout**: Twin forward tractors (Counter-Rotating).
* **Recommended Motors**: 2× BrotherHobby 2806.5 (1300KV on 6S or 1700KV on 4S).
* **Propellers**: 2× APC 7x5E or 7040 Long Range (1× CW, 1× CCW).
* **ESC**: 2× 45A AM32 / BLHeli_32 ESCs with 35V 1000µF Low-ESR capacitors.
* **Battery**: 4S2P or 6S1P 21700 Molicel P45B pack (4500–9000mAh, ~600g) $\rightarrow$ **60–90 min flight time**.
* **Cruising Current**: ~6A – 8A total at 65 km/h.

---

### 6. 🛸 Urumi (Experimental Hybrid VTOL Quadplane)
* **Goal**: Vertical hover, hover-to-wing transition, no control surfaces.
* **Propulsion Layout**: 4× Brushless motors (Quad X layout on 22° dihedral wings).
* **Recommended Motors**: 4× BrotherHobby 2806.5 (1950KV on 4S) or T-Motor F80 Pro 2408 (1900KV).
* **Propellers**: 4× Gemfan 7040 2-Blade or HQProp 7x4x3 3-Blade (2× CW, 2× CCW).
* **ESC**: 4-in-1 55A–65A BLHeli_32 / AM32 ESC (e.g., SpeedyBee 55A 4-in-1).
* **Battery**: 4S 1500mAh – 2200mAh 100C–150C LiPo (Tattu R-Line or CNHL Black Series).
  * ⚠️ *Li-ion strictly prohibited*: Hover current draws 70A–90A total; Li-ion cells will instantly hit low-voltage cutoff.
* **Flight Time**: 6–8 minutes total (mix of 1.5 min hover/transition + 5 min wing cruise).

---

## 3. Practical Wiring & Connector Standard

| Current Level | Battery Connector | Main Wire Gauge | Motor Wire Gauge | Typical Use |
| :--- | :---: | :---: | :---: | :--- |
| **< 30A Continuous** | **XT30** | 16 AWG | 20 AWG | Mini Rifter (single motor) |
| **30A – 60A Continuous** | **XT60** | 14 AWG | 18 AWG | Rifter 3, Scimitar 3, Sabre |
| **60A – 120A Peak** | **XT60 / XT90** | 12 AWG | 16 AWG | Sica (Twin), Urumi (Quad VTOL) |

---

## 4. 📚 Authoritative References & Citations

1. **Battery Mooch**: *"Molicel P42A and P45B 21700 Benchmarks & Continuous Discharge Ratings"* — Independent laboratory testing verifying 45A CDR, internal resistance, and voltage sag characteristics. [[Mooch's Test Blog](https://www.e-cigarette-forum.com/forum/blog-entry/list-of-battery-tests.7436/)]
2. **Oscar Liang**: *"Why Capacitors Are Important For FPV Drones: Voltage Spikes and Filtering"* — Explains inductive back-EMF, low-ESR requirements, and Panasonic FM/FR and Rubycon ZLH capacitor sizing. [[Oscar Liang](https://oscarliang.com/capacitors-mini-quad/)]
3. **Oscar Liang**: *"Motor Size, Stator Dimensions, and KV Explained"* — Comprehensive tutorial on motor stator volume, torque vs RPM, and propeller matching. [[Oscar Liang](https://oscarliang.com/motors/)]
4. **AM32 / BLHeli_32 Architecture Documentation**: *"Sinusoidal Startup and Variable PWM Frequency for Fixed-Wing Efficiency"* — Multi-rotor and fixed-wing ESC commutation optimization. [[AM32 GitHub](https://github.com/AlkaMotors/AM32-MultiRotor-ESC-firmware)]
5. **Olivier_C**: *"Rifter, Sabre, Scimitar, Urumi Flight Logs"* — Verified real-world thrust-to-weight, current draw, and propeller sizing logs. [[RCGroups Thread #4223695](https://www.rcgroups.com/forums/showthread.php?4223695-Rifter-Sabre-Scimitar-mini-sized-FPV-cruisers)]

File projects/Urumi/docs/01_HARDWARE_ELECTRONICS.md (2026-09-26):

# ⚡ Hardware Electronics & Configuration Software Guide

> **Urumi VTOL Hybrid** — Complete guide for electronic components, wiring specifications, and software tools for configuring ESCs, brushless motors, flight controller, tilt servo, FPV, and radio receiver.

---

## 1. Software Tools for ESC, Motor & Avionics Configuration

To configure, test, and tune the electronics, use the following specialized software tools:

```mermaid
flowchart LR
    subgraph PC["💻 Ground Station / Configuration Tools"]
        SW1["<b>ESC-Configurator / BLHeli32</b><br/>(Motor Direction, 48kHz, Timing)"]
        SW2["<b>INAV Configurator (v7.x)</b><br/>(Dual Mixer, VTOL, PIDs, RTH)"]
        SW3["<b>ExpressLRS Configurator</b><br/>(Binding Phrase, Packet Rate)"]
        SW4["<b>DJI Assistant 2</b><br/>(Activation, Firmware, MSP Canvas)"]
    end

    subgraph AIR["🛸 Urumi Onboard Avionics"]
        ESC["4-in-1 ESC"]
        FC["Flight Controller"]
        RX["ELRS Receiver"]
        VTX["DJI O3/O4 Air Unit"]
    end

    SW1 -.->|USB Passthrough| ESC
    SW2 <--->|USB-C (VCP)| FC
    SW3 <--->|WiFi / UART| RX
    SW4 <--->|USB-C Direct| VTX
```

---

### 1.1 ESC & Motor Configuration Software

You do **not** need to unsolder motor wires to reverse spin directions. The flight controller connects via **USB passthrough** directly to the 4-in-1 ESC.

#### Tool 1: [ESC-Configurator.com](https://esc-configurator.com) (Recommended for BLHeli_S / Bluejay / AM32)
* **How to run**: Open Google Chrome, Brave, or Microsoft Edge, navigate to `https://esc-configurator.com`, plug your flight controller via USB, and power the ESC with a flight battery.
* **Key capabilities**:
  * **Motor Direction**: Click to reverse spin direction for any motor without swapping solder pads.
  * **Firmware Flashing**: Flash **Bluejay** firmware onto BLHeli_S ESCs to enable bi-directional DShot and RPM filtering.
  * **PWM Frequency**: Set PWM frequency to **48 kHz** (greatly improves motor efficiency, reduces heat, and extends hover time compared to default 24 kHz).
  * **Motor Beeping**: Enable beacon beeps so motors sound an acoustic alarm if the aircraft is lost in tall grass.

#### Tool 2: BLHeliSuite32 / [BLHeli32 Web](https://open-txu.org/blheli32-configurator/) (For BLHeli_32 ESCs)
* **How to run**: Windows standalone executable (`BLHeliSuite32.exe`) or web-based configurator.
* **Key settings**:
  * **Motor Protocol**: Set to **DShot600** or **DShot300**.
  * **Motor Timing**: Set to `Auto` or `16°–20°` for large 2806.5 / 2807 stator motors.
  * **Rampup Power**: Set to 25%–35% for smooth, high-torque motor startup with 7-inch props.
  * **Brake on Stop**: Enabled.

---

### 1.2 Flight Controller Software: [INAV Configurator](https://github.com/iNavFlight/inav-configurator/releases)

The core brain of the hybrid aircraft is managed entirely via **INAV Configurator** (Version 6.x or 7.x):

* **Firmware Flasher**: Flash the target firmware (e.g. `SPEEDYBEEF405WING` or `MATEKF405TE`).
* **Ports Tab**:
  * Allocate **UART1** for DJI MSP DisplayPort OSD.
  * Allocate **UART2** for ExpressLRS Serial RX (CRSF protocol).
  * Allocate **UART3** for GPS Module (115200 baud).
  * Enable **I2C** for external compass.
* **Configuration Tab**:
  * Enable Barometer, Magnetometer (Compass), and Accelerometer.
  * Set physical board alignment (FC arrow points forward to the nose).
* **Motors Tab**:
  * Motor protocol: `DSHOT300` or `DSHOT600`.
  * Verify motor order (Quad-X layout: M1 Rear Right, M2 Front Right, M3 Rear Left, M4 Front Left).
  * Safe Motor Testing: Use the master slider (with **props off!**) to verify all 4 motors spin correctly.
* **Outputs Tab**:
  * Route servo output **S5** to the camera tilt mechanism.
* **Modes Tab**:
  * Map your 3-position transmitter switch (CH8) to `Mixer Profile 1` / `Mixer Profile 2`.

---

### 1.3 Radio Link: [ExpressLRS Configurator](https://www.expresslrs.org/)
* Flash the latest ELRS firmware to the receiver.
* Enter your unique **Binding Phrase** so your transmitter and receiver pair instantly without manual bind buttons.
* Alternatively, power the receiver without turning on the transmitter; after 30 seconds, it enters Wi-Fi mode. Connect to `ExpressLRS RX` Wi-Fi on your phone or PC and browse to `http://10.0.0.1`.

---

### 1.4 FPV Video: DJI Assistant 2 (Consumer Drones Series)
* If using the **DJI O3 or O4 Air Unit**, download *DJI Assistant 2 (Consumer Drones Series)* from the DJI website.
* Connect via USB-C to activate the unit and update to the latest firmware.
* In the DJI Goggles menu, enable **MSP Canvas mode** to display the INAV OSD (groundspeed, battery voltage, horizon bar, and active mixer profile).

---

## 2. Complete Electronics Component Breakdown

```mermaid
flowchart TD
    BAT["🔋 <b>Flight Battery (4S–6S LiPo)</b>"] -->|XT60 Main Power| ESC["⚡ <b>45A–60A 4-in-1 ESC</b><br/>(Central Stack)"]

    ESC -->|3-Phase Motor Power| M1["⚙️ <b>Motor 1</b> (Top L)"]
    ESC -->|3-Phase Motor Power| M2["⚙️ <b>Motor 2</b> (Top R)"]
    ESC -->|3-Phase Motor Power| M3["⚙️ <b>Motor 3</b> (Bot L)"]
    ESC -->|3-Phase Motor Power| M4["⚙️ <b>Motor 4</b> (Bot R)"]

    ESC -->|VBAT + Current + Telemetry| FC["🧠 <b>INAV Flight Controller (F405 / F722)</b>"]

    FC -->|PWM S1-S4| ESC
    FC -->|PWM S5| SERVO["📐 <b>Camera Tilt Servo</b><br/>(EMAX ES08MA II)"]
    FC <-->|UART1 (MSP OSD)| FPV["🎥 <b>DJI O3 / O4 Air Unit</b><br/>(Digital HD Video)"]
    FC <-->|UART2 (CRSF)| RX["📶 <b>ExpressLRS 2.4GHz Receiver</b>"]
    FC <-->|UART3 (115200)| GPS["🧭 <b>GPS Module</b><br/>(U-blox SAM-M10Q)"]
    FC <-->|I2C1 (SCL/SDA)| COMP["🧭 <b>Magnetometer Compass</b><br/>(QMC5883L / IST8310)"]
```

---

### 2.1 Brushless Propulsion Motors (4 Required)

Urumi relies completely on differential thrust across its 4 motor nacelles for steering in forward flight.

| Propulsion Setup | Recommended Stator Sizes | 4S Voltage KV | 6S Voltage KV | Recommended Propeller | Characteristics |
| :--- | :--- | :---: | :---: | :--- | :--- |
| **7-Inch Setup (Recommended)** | 2806.5, 2807, 2507, or 2306.5 | **1600 – 1950 KV** | **1250 – 1500 KV** | Gemfan 7040 bi-blade / HQProp 7x4x2 | Superior hovering efficiency, low noise, high forward cruising thrust. |
| **6-Inch Setup (Agile/Sport)** | 2207 or 2306 | **2400 – 2550 KV** | **1750 – 1950 KV** | HQProp 6x4 bi-blade / Gemfan 6042 | Higher acceleration, aggressive climb, smaller footprint. |

#### Top Recommended Motor Models:
* **7" Cruiser**: *BrotherHobby Avenger 2806.5*, *Emax ECO II 2807*, *T-Motor Velox V3 2306*.
* **6" Sport**: *T-Motor F60 Pro IV*, *iFlight XING2 2207*, *Emax ECO II 2306*.

---

### 2.2 Electronic Speed Controllers (ESCs)

* **Form Factor**: **4-in-1 ESC** (30.5×30.5mm or 20×20mm mounting).
* **Current Rating**: **45A to 60A continuous** (burst 65A+).
* **Firmware**: BLHeli_32, BLHeli_S (flashed to Bluejay), or AM32.
* **Recommended Models**:
  * *SpeedyBee 50A 4-in-1 ESC* (Budget, high performance, robust solder tabs).
  * *Holybro Tekko32 F4 50A 4-in-1* (Premium BLHeli_32, metal heatsink, excellent telemetry).
  * *Skystars KM55A 32Bit 4-in-1*.

---

### 2.3 Flight Controller (FC)

The FC must support INAV VTOL dual-mixer profiles and feature onboard barometer and dedicated servo power:

| Model | Mounting | Built-in BEC | Why It Fits Urumi |
| :--- | :---: | :---: | :--- |
| **SpeedyBee F405 WING APP** | Universal | 5V 5A & 9V 2A | Engineered specifically for VTOL / Fixed-wing; wireless Bluetooth setup via mobile phone app. |
| **Matek F405-VTOL / F405-WTE** | 30.5×30.5 | 5V 5A & 9V/12V 2A | Dedicated hybrid VTOL flight controller with dual BEC rails and native INAV profiles. |
| **SpeedyBee F405 V4 Multirotor Stack** | 30.5×30.5 | 5V 2A & 9V 2A | Compact multirotor stack; requires routing servo power to a separate 5V BEC. |

---

### 2.4 Tilt Mechanism Servo

* **Type**: Standard 9g micro metal-gear servo.
* **Model**: **EMAX ES08MA II** (Analog or Digital) or *Corona DS-929MG*.
* **Specifications**:
  * Operating Voltage: 4.8V – 6.0V
  * Torque: 1.8 kg/cm @ 4.8V (plenty of holding power against high-speed aerodynamic wind resistance).
  * Mounting Hole Pitch: **27.6 mm** (exact match for the pre-drilled holes in `Servo Plate`).

---

### 2.5 Navigation & Rescue (GPS + Compass)

Urumi requires an external GPS and digital compass module for automated Return-to-Home (RTH), position hold, and orientation recovery:

* **Recommended Models**:
  * **Matek M10Q-5883**: High-sensitivity u-blox SAM-M10Q GNSS receiver with onboard QMC5883L digital compass.
  * **Holybro Micro M10 GPS**: Includes IST8310 compass, fast satellite acquisition (GPS, Galileo, GLONASS, BeiDou).
* **Wiring**:
  * TX/RX wired to FC UART3 (GPS data).
  * SCL/SDA wired to FC I2C bus (Compass data).
  * 5V and GND.

---

### 2.6 FPV Camera & Video Transmitter (VTX)

* **Primary System (Direct Fit)**: **DJI O3 Air Unit** or **DJI O4 Air Unit**.
  * The camera cage in `Camera mount` has an internal width of **20.2 mm**, designed specifically for DJI O3/O4 camera modules.
* **Alternative Systems (19mm Micro Cameras)**:
  * **Walksnail Avatar HD Pro Micro** / **Caddx Vista Nebula Pro** / **RunCam Phoenix 2 (Analog)**.
  * Add a 0.5mm 3D-printed washer or nylon shim on each side to span the 20.2mm bracket.

---

### 2.7 Radio Receiver & Flight Batteries

* **Radio Receiver**:
  * **ExpressLRS (ELRS) 2.4GHz Diversity Receiver** (e.g. *RadioMaster RP3* or *BetaFPV SuperD*). Dual antennas ensure seamless signal reception whether the plane is sitting vertically in hover or banking horizontally.
* **Battery Configurations**:
  * **Acro & Sport Flying**: **4S 1500mAh – 2200mAh (100C)** LiPo (~180g – 240g). Gives ~5–7 minutes of spirited mixed flying.
  * **High-Efficiency Long Cruise**: **4S1P 21700 Li-Ion (4200mAh – 4500mAh)** built with *Molicel INR21700-P42A* or *P45B* cells (~290g). Once transitioned onto its wings, the low current draw enables 20–30+ minutes of cruising.
  * **6S Option**: 6S 1300mAh – 1800mAh 100C LiPo (when using 6S low-KV motors).

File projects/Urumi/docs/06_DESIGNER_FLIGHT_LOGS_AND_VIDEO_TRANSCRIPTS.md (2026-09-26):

# 🎬 Designer Flight Logs, Video Transcripts & Development History

> **Project Source**: Designed by Olivier (*RCGroups: ["Rifter, Sabre, Scimitar mini-sized FPV cruisers"](https://www.rcgroups.com/forums/showthread.php?4223695-Rifter-Sabre-Scimitar-mini-sized-FPV-cruisers)*).  
> This document integrates the complete development history, technical insights, crash investigations, and video transcripts across the official 3-part YouTube video series.

---

## 📺 Official Video Series Reference

| Video Part | Title | Link | Key Milestones & Topics |
| :--- | :--- | :--- | :--- |
| **Part 1** | *Urumi, Quad/Interceptor/X-Wing 1* | [Watch on YouTube](https://www.youtube.com/watch?v=R3-GTveqTRI) | Prototype introduction, 22° wing dihedral design, removable wing mechanism, initial hover, first transition onto wings (70–80 km/h), first crash landing. |
| **Part 2** | *Urumi, Quad/Interceptor/X-Wing 2* | [Watch on YouTube](https://www.youtube.com/watch?v=sHy94xdoC1A&t=772s) | Second crash investigation (FC IMU thermal failure), redesigning to the final CAD release (wider landing pads, air intakes, VTX bay), F722 stack upgrade, INAV radar formation flight. |
| **Part 3** | *Urumi, Quad/Interceptor/X-Wing 3* | [Watch on YouTube](https://www.youtube.com/watch?v=J87EU8D0PFA) | Final flight tests with DakeFPV F722 stack, extreme wind sensitivity (5–6 km/h limit), honest pilot handling evaluation. |

---

## 1. Part 1: Conception, First Flights & Transition Test

### 1.1 Aerodynamic & Structural Architecture
* **Hybrid Concept**: The aircraft can be viewed as an aeroplane with unusually small wings and four propulsion motors, or as a quadcopter whose wings generate aerodynamic lift once forward airspeed is reached.
* **Wing Dihedral (22° Angle)**: The 22° dihedral was calculated precisely to allow clearance for 7-inch propellers while keeping the propeller thrust discs as horizontal as possible to preserve vertical hover efficiency.
* **Effective Wing Area**: Four wings measuring 20 × 20 cm each provide a total area equivalent to a single 80 × 20 cm wing.
* **Modular Glueless Wings**: In the very first prototype, the wings were glued to the fuselage. The designer subsequently redesigned the fuselage so the wings slide freely over the 6.0mm carbon spars and are locked by the motor mounts (`Wing lock`). This allows rapid replacement or testing of longer wing extensions.
* **Materials**: Airframe 3D-printed in PLA+ (ePLA-ST) assembled with cyanoacrylate (CA) and spray accelerator. Hollow 6mm carbon fiber tubes form the central X-frame.
* **Tilting FPV Camera**: Servo-actuated mount compatible with the DJI O3 and DJI O4 video systems.

### 1.2 Initial Flight & Hover Test
* Tested in breezy conditions. Despite small 6-inch test propellers and older 2206 motors, the aircraft hovered stably.
* **Passive Weathercock Stability**: The large rear fuselage acts as a weather vane, automatically turning the nose into the wind.

### 1.3 The First Transition & Wing-Borne Flight
* Operating on a standard quadcopter mixer, forward pitch was applied. To the team's delight, the aircraft accelerated and transitioned onto its wings at approximately **70–80 km/h** without requiring an excessive angle of attack.
* **Flight Controls**:
  * Turning with roll alone is inefficient due to lack of ailerons; the aircraft makes very wide turns.
  * **Coordinated yaw + roll** produces effective, tighter turns.
  * **Flat yaw turns**: Using yaw alone creates differential thrust across the left and right motors, rotating the aircraft around its vertical axis with zero bank angle (like a high-speed camera drone).

### 1.4 The Landing Crash (Disorientation Incident)
* **What Happened**: At the end of the second flight, the pilot believed the camera was tilted to 45°, when it was actually pointing straight forward at 0°. Misjudging the aircraft's true attitude, the pilot entered a steep dive in Acro mode, expecting to pull out near the ground.
* **Root Cause**: The hybrid aircraft's mass and wing drag do not respond with the instantaneous snap-recovery of a lightweight racing quad. The aircraft struck the rocky ground nose-first.
* **Damage**: Minor structural damage; the wings survived because they were removable.

---

## 2. Part 2: Crash Investigation, Evolution to Final CAD Release & Radar Cruise

### 2.1 The Second Crash: Flight Controller IMU Failure
During subsequent testing, a second crash occurred:
> *"Second plane broken because of this faulty flight controller. Maybe IMU issue, overheats or whatever and dies. Works at take off, then fails after a few minutes."*

### 2.2 Transition to F722 Stack & 4-in-1 ESC
In the initial prototype, the designer used 4 separate ESCs and an intermediate Power Distribution Board (PDB), which created a tangled nest of cables inside the fuselage.  
* **Upgrade**: The designer switched to an **F722 flight controller stack with a 4-in-1 ESC**, greatly simplifying internal wiring, reducing weight, and eliminating the cable clutter.

### 2.3 Airframe Modifications in the Final CAD Release
The designer incorporated several critical design improvements into the final files published on RCGroups (which match the files in this repository):
1. **Wider Landing Pads (`Pad 1, 2, 3, 4`)**: All 4 pads are now asymmetrical, widening the stance so the aircraft does not tip over when settling vertically onto uneven grass or gravel.
2. **Integrated Cooling Air Intakes**: Openings added to the fuselage nose to channel airflow directly over the ESC, FC, and VTX.
3. **Internal Plate Optimization**: Repositioned `FC Plate` and `Battery Plate` to create a dedicated compartment for the DJI O3 / O4 video transmitter.

### 2.4 Formation Flying with INAV Radar & Cruise Efficiency
* In Video 2, the designer performs dusk formation flights with a wingmate using the **INAV Radar** feature on their OSD.
* **Cruise Consumption**: In level forward flight, the aircraft draws only **~8 Amps** at cruising speed.
* **Efficiency**: Approximately **60 mAh per kilometer** on a 4S/5S LiPo battery, allowing ~15 minutes of forward flight on a 2200mAh pack.

---

## 3. Part 3: Final Flight Tests with DakeFPV F722 & Handling Limits

### 3.1 Flight Controller Replacement
* The designer installed a budget **DakeFPV F722** stack from AliExpress. In flight testing, the new board performed reliably with zero sensor lockups or overheating issues.

### 3.2 Environmental Limits: Extreme Wind Sensitivity
> ⚠️ *"If there is one thing this aircraft hates, it is wind. 5 to 6 km/h of wind is already too much—it completely disturbs it."*
* **Why**: The high surface area of the fuselage, four angled wings, and large vertical fin make hovering in wind turbulent. Ground turbulence near trees causes erratic drift. Always maiden and fly Urumi in calm or light-breeze conditions.

### 3.3 Honest Handling Summary from the Designer
Olivier provided an entertaining yet candid evaluation of the aircraft's dual nature:
> *"It's the worst quad in my fleet, and it's also the worst airplane! It's the combination of the two: a bad quad with a bad plane. It can do both. Landing it is not fun at all; however, launching and taking off is super fun! The rest is tricky, but I haven't finished the tuning yet..."*

---

## 4. Key Takeaways & Actionable Lessons for Builders

1. **Electronics Stack**: Use a modern **F722 or F405 flight controller with a 4-in-1 ESC** (rather than individual ESCs) to keep the fuselage clean and avoid IMU overheating.
2. **Attitude Awareness**: Set up your FPV OSD to clearly display:
   * Current Mixer Profile (`PROF 1` / `PROF 2`)
   * Camera tilt angle
   * Artificial horizon line
3. **Landing Discipline**: Never attempt a forward Acro descent. Always switch to **Position 2** (45° camera) to bleed off speed, then switch to **Position 1** (90° camera, Quad-X mode) and land vertically like a multirotor.
4. **Weather Condition**: Only fly in calm weather (<6 km/h wind).
5. **Turns**: Always coordinate your sticks (**Roll + Yaw together**) in forward flight.

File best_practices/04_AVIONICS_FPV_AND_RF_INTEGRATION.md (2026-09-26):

# 📡 Guide 04: Avionics, FPV & RF Integration




A 3D-printed aircraft is an RF-dense environment. With a GPS receiver, digital compass, video transmitter, radio receiver, camera, and high-current motor cables packed into a confined plastic fuselage, **electromagnetic interference (EMI)** and **RF crosstalk** can easily cause GPS lock failure, compass drift, or control link failsafes if components are not strategically laid out.

This guide provides proven avionics integration and RF separation standards for the **AeroBlades** fleet.

---

## 1. Flight Controller Selection & Mounting

| Platform | Recommended Flight Controllers | Firmware Support | Target Airframes |
| :--- | :--- | :---: | :--- |
| **Standard Wing FC** | **Matek F405-WMN / WTE**, **SpeedyBee F405 Wing** | INAV / ArduPilot | **Mini Rifter**, **Rifter 3**, **Sabre**, **Scimitar 3** |
| **Heavy / Multi-Servo**| **Matek H743-WING**, **Matek F405-WING V2** | INAV / ArduPilot | **Sica** (Twin rudders, twin ailerons, elevator, LED channels) |
| **Quadplane / VTOL** | **DakeFPV F722 VTOL / AIO**, **Matek H743-WLITE** | INAV VTOL / ArduPilot | **Urumi** (4-motor differential quadplane mixer) |

### Mounting & Vibration Isolation:
* **Never hard-mount a flight controller with rigid metal screws to printed plastic.**
* Use **M2 or M3 soft silicone anti-vibration bobbins/grommets**.
* High-frequency motor vibrations transmitted through the stiff plastic airframe can saturate the internal gyro/accelerometer (IMU), causing erratic auto-leveling and violent roll oscillations.

---

## 2. GPS & Compass (Magnetometer) Hygiene

The internal digital magnetometer (compass) measures Earth's tiny magnetic field (~0.5 Gauss). Any high-current DC wire passing nearby acts as an electromagnet ($B \propto I / r$), causing severe compass deflection whenever throttle is applied.

```mermaid
flowchart TD
    GPS["🧭 <b>GPS & Digital Magnetometer (Compass)</b><br/>(Mounted on top boom, elevated fairing, or rear mast)"]
    
    subgraph HIGH_EMI["⚠️ High-Current EMI Zone"]
        direction LR
        BAT["🔋 Battery Leads"] <--> ESC["⚡ ESC / PDB Traces"] <--> MOT["⚙️ Motor Phase Wires"]
    end
    
    GPS <-.->|"<b>MINIMUM 60mm – 80mm CLEARANCE</b><br/>(Prevents Magnetic Field Deflection)"| HIGH_EMI
```

### Essential Rules for Compass Placement:
1. **Physical Elevation**: Mount the GPS module on the top fairing, rear tail boom, or dedicated GPS plate (as included in `projects/Common/` and `projects/Rifter_3/Extras/`).
2. **Twist Power Wires**: Tightly twist the positive and negative battery leads together. Opposing currents cancel out their external magnetic fields!
3. **Compass Calibration**: Always perform compass calibration outdoors, far away from reinforced concrete buildings, steel fences, and automobiles.

---

## 3. Digital FPV Integration (DJI O3 / Walksnail / HDZero)

Modern digital FPV systems generate crystal-clear HD video, but they introduce two distinct engineering challenges: **heat generation** and **RF noise**.

### 1. Thermal Dissipation
* The DJI O3 Air Unit and Walksnail VTX consume 10W–15W of power and quickly reach thermal throttling limits (80°C+) when stationary on the ground.
* **Standard Mounts**: Always use the ventilated brackets from [`projects/Common/02_DJI_O3_Mounts/`](../projects/Common/):
  * `DJI O3 VTX mount.3mf`: Features cooling scoops and heatsink exposure.
  * *Tip*: Avoid leaving the plane powered on the ground for more than 2 minutes before launch without active cooling or a small 5V USB fan.

### 2. Camera Jello Mitigation
* CMOS digital sensors (DJI O3, Walksnail) are vulnerable to "Jello" (horizontal rolling shutter wavy artifacts) caused by motor unbalance.
* Use the **`DJI O3 cage 1.3mf` & `2.3mf`** from `projects/Common/`, which incorporates soft rubber or TPU vibration grommets between the camera bracket and the fuselage nose.
* Balance all propellers dynamically before flight!

---

## 4. Radio Control (RC) Link & Antenna Separation

ExpressLRS (ELRS 2.4GHz / 868-915MHz) and TBS Crossfire provide extraordinary range, but antenna placement dictates link quality:

```mermaid
flowchart LR
    CAM["🎥 FPV Camera<br/>(Fuselage Nose)"] --- VTX["📡 5.8GHz VTX Antenna<br/>(Rear Boom or Wingtip)"]
    
    VTX <-.->|"<b>MINIMUM 80mm – 120mm AIR GAP</b><br/>(Prevents Receiver Front-End De-sensing)"| RX["📶 RC Receiver T-Antenna<br/>(Vertical Polarization)"]
```

### Optimal Antenna Layout:
1. **Vertical Polarization**:
   * Mount the receiver antenna **vertically** (pointing straight up or down).
   * Most ground transmitter antennas are held vertically; matching antenna polarization avoids a **20dB signal attenuation penalty**.
2. **Frequency Separation**:
   * **2.4GHz ELRS + 5.8GHz Video**: Excellent combination with zero harmonic overlap.
   * **868/915MHz ELRS + 5.8GHz Video**: Maximum penetration and long-range immunity.
3. **Keep Antennas Off Carbon Tubes**:
   * Carbon fiber is electrically conductive and acts as an RF reflector/shield.
   * Never tape receiver or video antennas directly against carbon spars—leave at least 15mm of plastic or foam standoff.

---

## 5. Software & Autopilot Setup Checklist (INAV / ArduPilot)

Before launching any AeroBlades aircraft:

1. **Verify Control Surface Direction (MANUAL Mode)**:
   * Stick Left $\rightarrow$ Left aileron UP, Right aileron DOWN.
   * Stick Back (Pitch Up) $\rightarrow$ Elevators/Elevons UP.
2. **Verify Autopilot Correction Direction (STAB / ANGLE Mode)**:
   * Tilt plane left by hand $\rightarrow$ Flight controller must deflect left aileron DOWN (counteracting the bank).
   * Tilt nose down by hand $\rightarrow$ Flight controller must deflect elevator UP.
3. **Calibrate Current Sensor**:
   * Accurately measure consumed mAh to avoid over-discharging Li-ion packs in long-range cruise.
4. **Program Automatic Return-to-Home (RTH)**:
   * Set RTH altitude at least 30m above local trees/terrain.
   * Configure failsafe action to **RTH** instead of immediate drop.

---

## 6. 📚 Authoritative References & Citations

1. **ExpressLRS Documentation**: *"Antenna Orientation, Polarization, and Placement Best Practices"* — Outlines linear polarization alignment, diversity orthogonal placement, and conductive carbon standoff rules. [[ExpressLRS Docs](https://www.expresslrs.org/)]
2. **ArduPilot Documentation**: *"Compass Setup and Advanced Magnetic Interference Mitigation (CompassMot)"* — Physics of magnetic field deflection from high-current motor traces ($B \propto I / r$). [[ArduPilot Docs](https://ardupilot.org/copter/docs/common-compass-setup-advanced.html)]
3. **INAV Documentation**: *"Fixed-Wing Autolaunch, PIFF Tuning, and Safe Return-to-Home"* — Technical wiki for fixed-wing PID controller tuning and emergency recovery logic. [[INAV Wiki](https://github.com/iNavFlight/inav/wiki)]
4. **Oscar Liang**: *"FPV Drone Antenna Placement Rules & Signal Degradation"* — Radiation patterns of dipole antennas and polarization loss factors. [[Oscar Liang](https://oscarliang.com/)]

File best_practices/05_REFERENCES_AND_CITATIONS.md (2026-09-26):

# 📖 Guide 05: References, Citations & Authoritative Sources




The engineering rules, material recommendations, and electronics guidelines documented throughout the **AeroBlades Best Practices Suite** are grounded in empirical testing, manufacturer technical data sheets (TDS), independent laboratory benchmarks, and established aerospace/FPV community standards.

This document compiles the authoritative internet sources, test archives, and technical references underpinning this repository.

---

## 1. 3D Printing Materials & Mechanical Testing

### 🔬 CNC Kitchen (Stefan Hermann) — Empirical Mechanical Testing
* **"Testing Foaming Filaments: Mass Savings vs. Mechanical Strength"**  
  *Source:* [CNC Kitchen YouTube & Blog](https://www.cnckitchen.com/)  
  *Key Finding:* Demonstrates that active-foaming filaments (LW-PLA and LW-ASA) trade away up to 40%–50% of their inter-layer tensile strength and shear modulus in exchange for mass reduction. Concludes that high-stress functional components (motor mounts, latches, control horns) should always remain solid non-foaming materials (PLA+, PETG, or standard ASA), with carbon fiber spars used to provide primary bending and torsional rigidity.
* **"Layer Adhesion vs. Nozzle Temperature in FDM 3D Printing"**  
  *Source:* [CNC Kitchen Material Testing Database](https://www.cnckitchen.com/blog/layer-adhesion-temperature)  
  *Key Finding:* Higher print temperatures (e.g., 215°C–225°C for PLA+) significantly improve polymer chain entanglement across layers, yielding up to 30% higher Z-axis tensile strength—critical for thin-wall aircraft wings.

### 🏭 Manufacturer Technical Data Sheets (TDS) & Foaming Guides
* **colorFabb: LW-ASA (Lightweight ASA) Technical Guidelines**  
  *Source:* [colorFabb LW-ASA Documentation](https://learn.colorfabb.com/)  
  *Key Parameter:* Active foaming begins at ~230°C and reaches maximum expansion at 250°C–260°C, increasing volume up to 2.5× (density drops from 1.07 g/cm³ to ~0.55–0.65 g/cm³). Recommends lowering extrusion flow multiplier to 45%–60% and printing inside an enclosed chamber at 45°C+ to mitigate warping.
* **colorFabb: LW-PLA Printing & Slicing Manual**  
  *Source:* [colorFabb LW-PLA Technical Guide](https://learn.colorfabb.com/how-to-print-with-lw-pla/)  
  *Key Parameter:* Outlines the temperature-dependent density curve and highlights why active foaming materials are best suited for single-wall aerodynamic shells with zero retract or minimal retraction (1–2mm) to prevent hotend clogging.
* **Polymaker: PolyLite Light Weight PLA Data Sheet**  
  *Source:* [Polymaker Industrial & Consumer TDS](https://polymaker.com/)  
  *Key Parameter:* Explains pre-foamed (stabilized micro-balloon) PLA technology: achieves ~0.80 g/cm³ without temperature-activated foaming, offering superior print fidelity, zero stringing, and higher Young's modulus than active-foaming filaments.

---

## 2. Power Systems, Batteries & Electrical Safety

### 🔋 Battery Mooch (Independent Cell Benchmarking)
* **Molicel 21700 P42A & P45B Comprehensive Lab Tests**  
  *Source:* [Mooch's Battery Test Archive on E-Cigarette Forum](https://www.e-cigarette-forum.com/forum/blog-entry/list-of-battery-tests.7436/)  
  *Key Benchmark:*
  * **Molicel P42A**: 4000mAh min / 4200mAh typ, independently verified at **45A Continuous Discharge Rating (CDR)**. Proven baseline for high-current endurance packs.
  * **Molicel P45B**: 4500mAh typ, **45A CDR**, featuring ~33% lower internal resistance ($DC-IR$) than P42A, resulting in substantially lower voltage sag and cooler operation at high throttle.
* **Li-ion Voltage Sag Curve in Fixed-Wing Cruise**  
  *Source:* [Mooch: Voltage Cutoff and Cell Longevity Analysis](https://www.e-cigarette-forum.com/)  
  *Key Guidance:* High-density cylindrical cells can safely be discharged down to 2.80V–3.00V per cell under load, whereas standard pouch LiPos must never be drawn below 3.50V per cell.

### ⚡ Oscar Liang — FPV Electrical Engineering
* **"Why Capacitors Are Important for FPV ESCs"**  
  *Source:* [Oscar Liang: FPV Drone Capacitor Guide](https://oscarliang.com/capacitors-mini-quad/)  
  *Key Recommendation:* Fast motor braking and rapid PWM switching create violent inductive back-EMF voltage spikes that exceed component ratings. Mandates **low-ESR** capacitors (specifically **Panasonic FM/FR** or **Rubycon ZLH** series) soldered directly across the ESC power rails to protect sensitive 5V BECs and digital FPV transmitters.
* **"Choosing the Right Motor Size and KV for RC Planes"**  
  *Source:* [Oscar Liang FPV Knowledgebase](https://oscarliang.com/motors/)  
  *Key Recommendation:* Power-to-weight budgeting, thermal dissipation in enclosed fuselages, and why high-stator low-KV motors swinging larger propellers yield significantly higher thrust-per-watt efficiency in cruise.

---

## 3. Avionics, Antennas & RF Link Hygiene

### 📡 ExpressLRS (ELRS) Official Documentation
* **"Antenna Orientation, Polarization, and Placement Best Practices"**  
  *Source:* [ExpressLRS Official Hardware Wiki](https://www.expresslrs.org/)  
  *Key Principles:*
  * **Polarization Matching:** Linear dipole/T-antennas must maintain vertical alignment between transmitter and receiver to avoid a ~20dB cross-polarization signal penalty.
  * **Carbon Fiber Standoff:** Carbon is electrically conductive and attenuates RF. Active antenna elements must maintain at least **30mm clearance** from carbon tubes and large battery masses.
  * **Diversity Orthogonal Layout:** Dual-antenna receivers should orient elements at a 90° angle (L-shape) to eliminate antenna radiation null zones during banking turns.

### 🧭 INAV & ArduPilot Autopilot Frameworks
* **INAV Fixed Wing Official Guide & Documentation**  
  *Source:* [INAV GitHub Wiki & Docs](https://github.com/iNavFlight/inav/wiki)  
  *Key Guidance:* Comprehensive autolaunch configuration, PIFF controller tuning for flying wings and cruisers, fail-safe Return-to-Home (RTH) altitude parameters, and Li-ion fuel-gauge calibration.
* **ArduPilot: Compass Magnetic Interference (CompassMot) Documentation**  
  *Source:* [ArduPilot Compass Calibration Guide](https://ardupilot.org/copter/docs/common-compass-setup-advanced.html)  
  *Key Principle:* Explains how high-current DC traces generate magnetic fields according to Ampère’s law ($B \propto I / r$). Mandates physical separation of at least 60mm–100mm between compass sensors and battery/ESC power cables.

---

## 4. Primary Airframe Source & Designer Logs

### ✈️ RCGroups: Olivier_C FPV Cruiser Community
* **"Rifter, Sabre, Scimitar : mini-sized FPV cruisers" (Thread #4223695)**  
  *Source:* [RCGroups Forum Thread](https://www.rcgroups.com/forums/showthread.php?4223695-Rifter-Sabre-Scimitar-mini-sized-FPV-cruisers)  
  *Author:* **Olivier_C**  
  *Contribution:* Origin of the **AeroBlades** airframe geometries, thin-wall gyroid construction technique, carbon spar layout, and Bambu P1P flight-tested print profiles for Mini Rifter, Rifter 3, Sabre, Scimitar 3, Sica, and Urumi.

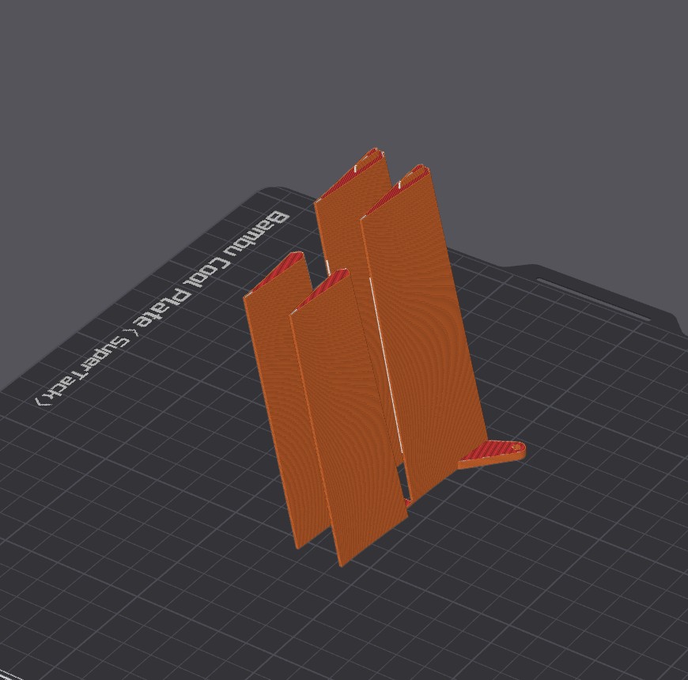
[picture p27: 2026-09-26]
projects/Scimitar_3/media/slicer_placement/Wing ailerons.jpg

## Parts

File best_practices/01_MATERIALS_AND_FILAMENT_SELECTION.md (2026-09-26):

# 🧪 Guide 01: Material & Filament Selection




Choosing the correct 3D printing material is the single most critical decision in manufacturing a 3D-printed aircraft. Unlike static ornamental prints, an aircraft airframe experiences continuous aerodynamic bending, torsional twisting, motor vibration, thermal exposure to direct sunlight, and high shock deceleration on landing.

This guide provides an engineering-grade evaluation of materials for the **AeroBlades** fleet, specifically dissecting the trade-offs between **Aero ASA (LW-ASA)**, **PLA+**, **LW-PLA**, **PETG**, and **TPU**.

---

## 1. The Core Dilemma: Stifness vs. Weight vs. Heat

A common misconception in 3D-printed aviation is that **lighter is always better**. In practical RC flight dynamics, this is only true if structural stiffness is preserved:

1. **Bending & Torsional Rigidity (Young's Modulus)**:
   When an aircraft dives at 80–120 km/h or pulls a 4G turn, the wings experience intense aerodynamic lift and torsional twisting (twist along the span). If the material has a low modulus of elasticity, the wing will twist dynamically, causing **aeroelastic flutter**—which strips servos or causes catastrophic structural failure.
2. **Inter-Layer Tensile & Shear Strength**:
   Active-foaming materials create a micro-cellular foam structure. While this cuts weight by up to 50%, it drastically weakens the bond between printed layers. Parts subjected to shear forces (wing locks, motor mounts, landing pads) snap easily.
3. **Glass Transition Temperature ($T_g$) & Thermal Creep**:
   Dark-colored PLA softens at approximately 55°C–60°C. In summer sun or inside a locked car (where interior cabin temperatures reach 65°C+), a thin PLA wing will permanently sag and distort under its own weight.

---

## 2. Comprehensive Material Comparison Matrix

| Filament Type | Density ($\text{g/cm}^3$) | Tensile Modulus (Stiffness) | Glass Transition ($T_g$) | Inter-layer Adhesion | UV / Weather Resistance | Slicer Ease of Print |
| :--- | :---: | :---: | :---: | :---: | :---: | :---: |
| **PLA+ / Tough PLA** | 1.24 | **Very High (~3.5 GPa)** | ~55°C – 60°C | **Exceptional** | Moderate (degrades in direct wet weather) | ⭐⭐⭐⭐⭐ (Zero warp, no enclosure needed) |
| **Aero ASA / LW-ASA** (e.g. ColorFabb LW-ASA) | **~0.60 – 0.75** (foamed) | **Low (~1.0 – 1.3 GPa)** | **High (~98°C – 105°C)** | Moderate | **Exceptional** (UV immune, zero sun fade) | ⭐⭐⭐ (Enclosed chamber required, warping risk) |
| **Active Foaming LW-PLA** (e.g. ColorFabb LW-PLA) | **~0.55 – 0.65** (foamed) | **Low (~1.0 GPa)** | ~55°C | Low | Poor | ⭐⭐⭐ (High stringing, temperature sensitive) |
| **Pre-Foamed LW-PLA** (e.g. Polymaker PolyLite LW) | ~0.80 – 0.85 (fixed) | Medium (~2.2 GPa) | ~58°C | Medium-High | Moderate | ⭐⭐⭐⭐ (Prints like standard PLA, no stringing) |
| **PETG / PETG-CF** | 1.25 – 1.27 | High (~2.6 – 3.2 GPa) | ~75°C – 80°C | **Very High** | High | ⭐⭐⭐⭐ (Slight stringing, good bed grip) |
| **Standard Solid ASA/ABS** | 1.05 – 1.08 | High (~2.3 – 2.6 GPa) | **High (~95°C – 105°C)** | High | **Exceptional** | ⭐⭐⭐ (Requires 45°C+ heated chamber) |
| **TPU 95A** | 1.20 | Flexible (Elastomer) | - | **Virtually Indestructible** | High | ⭐⭐⭐⭐ (Slow print speed, direct drive) |

---

## 3. Deep Dive: Should You Use Aero ASA (LW-ASA)?

### ✅ When Aero ASA is the BEST Choice:
* **Canopies & Top Hatches (`05_Canopy/`)**:
  The canopy is situated on top of the airframe, receives 100% of solar radiation, and houses electronics that generate internal heat. Printing canopies in Aero ASA saves significant weight high above the center of gravity while remaining completely immune to sun warping.
* **Non-Structural Fairings, GPS Mounts & Nose Bay Hatches**:
  Where parts only act as aerodynamic wind covers and do not carry flight bending loads.
* **Warm Climate Flight Operations**:
  If you regularly fly in ambient temperatures above 32°C (90°F) or store your models in vehicles, Aero ASA eliminates thermal sagging on exterior fairings.

### ❌ When Aero ASA is the WRONG Choice:
* **High-Speed Wing Panels (`02_Wings/`)**:
  Airframes like **Sabre** (twin-tractor, 120+ km/h) or **Scimitar 3** experience immense aerodynamic pressure. Aero ASA's low torsional modulus can result in severe wing flex and flutter unless you thicken walls significantly (which defeats the weight savings).
* **Motor Mounts (`03_Tail_and_Stabs/`, `03_Nacelles/`)**:
  Brushless motors generate operational heat (50°C–70°C) and violent rotational vibration. Under screw clamping force, foamed Aero ASA will suffer from **material creep**—the motor mounting screws will lose tension in flight, leading to motor detachment.
* **Wing Snap Latches & Spar Sockets**:
  The shear strength of active-foamed layers is roughly 40%–50% that of solid PLA+ or PETG. Hard landings will snap the retention teeth immediately.

---

## 4. Component-by-Component Material Assignment Matrix

```mermaid
flowchart TD
    Part["Aircraft Component Slicing Decision"]
    
    Part --> IsHinge{"Is it a flexible<br/>control surface hinge?"}
    IsHinge -- "YES" --> TPU["<b>TPU 95A (100% Solid)</b><br/>Tear-proof, zero-play flex hinge"]
    
    IsHinge -- "NO" --> IsStress{"Is it high stress / motor heat?<br/>(Motor mount, wing lock, skid)"}
    IsStress -- "YES" --> PETG["<b>PETG or Solid ASA (100%)</b><br/>Impact resistant, 85°C+ heat limit, no creep"]
    
    IsStress -- "NO" --> IsCover{"Is it an upper canopy,<br/>hatch or sun cover?"}
    IsCover -- "YES" --> ASA["<b>Aero ASA / LW-ASA</b><br/>50% weight savings, 100°C UV & sun immune"]
    
    IsCover -- "NO" --> WING["<b>PLA+ / Tough PLA</b><br/>1 Wall + 4% Gyroid, high torsional stiffness"]
```

Use this authoritative assignment matrix when slicing parts across any **AeroBlades** aircraft:

| Subsystem Component | Primary Recommended Material | Alternative Option | Strict Rule / Avoidance |
| :--- | :--- | :--- | :--- |
| **Wing Panels & Ailerons** | **PLA+ / Tough PLA** | Pre-Foamed LW-PLA (PolyLite) or Standard ASA | ❌ Never use Active Foaming LW-PLA on high-speed wings without carbon spar trusses |
| **Fuselage Electronics Bays** | **PLA+** | Standard ABS / ASA | ⚠️ Ensure adequate airflow vents for ESC and VTX cooling |
| **Canopies & Sun Hatches** | **Aero ASA (LW-ASA)** | Active Foaming LW-PLA or Standard PLA+ | ✅ Ideal use case for lightweighting and sun protection |
| **Motor Mounts & Nacelles** | **PETG** or **Standard Solid ASA** | High-temp PLA+ (if motors run cool) | ❌ **NEVER** use foaming materials (Aero ASA / LW-PLA) |
| **Wing Locks & Joiner Latches** | **PLA+** or **PETG** | Solid ASA | ❌ Never use lightweight or foaming filament |
| **Battery & Flight Controller Plates** | **PLA+** | PETG / Carbon-filled PLA | ❌ Avoid brittle silk filaments |
| **Landing Skids & Nose Skids** | **PETG** or **TPU 95A** | Solid PLA+ | ⚠️ Needs impact and abrasion resistance on grass/gravel |
| **Control Surface Hinges** | **TPU 95A** (100% Solid) | Nylon fabric hinge tape | ❌ Never print live hinges in rigid PLA or ASA |

---

## 5. Printing Tips & Slicer Profiles for Key Filaments

### A. Tuning Aero ASA (LW-ASA)
* **Chamber Temperature**: Enclosed printer required. Chamber temperature should reach at least **45°C–50°C** before starting to avoid warping and delamination on long spans.
* **Nozzle Temperature & Foaming**: Foaming activates between **230°C and 255°C**.
  * 230°C: Low foaming, higher tensile strength, density ~0.80 g/cm³.
  * 250°C: Maximum foaming, density ~0.60 g/cm³, reduced layer strength.
* **Flow Rate (Extrusion Multiplier)**: Set to **55% – 65%** at 250°C.
* **Shrinkage Compensation**: Scale X and Y dimensions by **100.8% – 101.2%** to ensure carbon spars slide smoothly into printed channels.

### B. Tuning PLA+ for High Rigidity
* **Nozzle Temperature**: 210°C – 220°C (higher temperature promotes superior layer fusion).
* **Cooling Fan**: 60% – 80% (avoid 100% fan on thin-wall perimeters to maintain maximum interlayer weld strength).
* **Flow Rate**: 98% – 100%.

### C. Tuning TPU 95A for Control Surface Hinges
* **Orientation**: Lay hinges completely flat on the build plate.
* **Walls & Infill**: 2–3 perimeter walls, **100% solid infill**.
* **Speed**: 25 – 35 mm/s on direct drive extruders. Ensure retraction is low (0.8–1.2mm) to prevent extruder jamming.

---

## 6. Recommended Filament Brands

* **PLA+**: eSun PLA+, Bambu Lab PLA Tough / Basic, Sunlu PLA+, Polymaker PolyMax PLA.
* **Aero ASA / LW-ASA**: ColorFabb LW-ASA, eSun LW-ASA.
* **Pre-Foamed PLA**: Polymaker PolyLite Light Weight PLA (no active foaming, prints with standard PLA settings).
* **PETG**: Bambu Lab PETG-CF, eSun PETG, Prusament PETG.
* **TPU**: Overture TPU 95A, Polymaker PolyFlex TPU95-HF, Bambu TPU 95A.

---

## 7. 📚 Authoritative References & Citations

1. **CNC Kitchen (Stefan Hermann)**: *"Testing Foaming Filaments: Mass Savings vs. Mechanical Strength"* — Demonstrates tensile capacity and inter-layer bond reduction in active-foaming LW materials. [[CNC Kitchen](https://www.cnckitchen.com/)]
2. **colorFabb Technical Documentation**: *"colorFabb LW-ASA Printing Guidelines"* — Expansion ratios, foaming temperature thresholds (230°C–260°C), and flow rate reduction curves. [[colorFabb Learn](https://learn.colorfabb.com/)]
3. **colorFabb Technical Documentation**: *"colorFabb LW-PLA Technical Guide"* — Slicing single-wall aerodynamic shells with zero retraction. [[colorFabb LW-PLA](https://learn.colorfabb.com/how-to-print-with-lw-pla/)]
4. **Polymaker**: *"PolyLite Light Weight PLA Technical Data Sheet"* — Fixed micro-balloon pre-foaming vs active chemical foaming mechanical comparison. [[Polymaker TDS](https://polymaker.com/)]
5. **Olivier_C**: *"Rifter, Sabre, Scimitar: mini-sized FPV cruisers"* — Airframe structural test logs and Bambu P1P print profiles. [[RCGroups Thread #4223695](https://www.rcgroups.com/forums/showthread.php?4223695-Rifter-Sabre-Scimitar-mini-sized-FPV-cruisers)]

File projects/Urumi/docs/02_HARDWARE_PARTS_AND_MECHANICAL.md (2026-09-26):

# 🔩 Hardware Parts, Mechanical Structure & Materials Guide

> **Urumi VTOL Hybrid** — Complete specifications for structural carbon fiber spars, fasteners, adhesives, 3D-printed airframe components, and filament mechanical properties.

---

## 1. Structural Carbon Fiber Backbone

The central structural strength of Urumi relies on an **X-shaped internal carbon-fiber frame** that ties the fuselage, wings, and motor nacelles into a single rigid assembly.

```
                    [Front-Left Motor]             [Front-Right Motor]
                             \                     /
                              \   6.0 x 284mm     /
                               \  Carbon Spar    /
                                +---------------+
                                |   FUSELAGE    |
                                +---------------+
                               /  Carbon Spar    \
                              /   6.0 x 284mm     \
                             /                     \
                    [Rear-Left Motor]              [Rear-Right Motor]
```

### 1.1 Carbon Tube Specifications
* **Quantity Required**: **4 pieces**
* **Outer Diameter (OD)**: **6.0 mm** (±0.05 mm tolerance)
* **Length**: **284.0 mm**
* **Inner Diameter (ID)**: ~4.0 mm (hollow pultruded carbon fiber tubing)
* **Wall Thickness**: ~1.0 mm
* **Weight**: ~11.5 grams per tube (~46 grams total for all 4 spars)

### 1.2 Cutting & Preparation Tips
1. Carbon fiber tubes are typically sold in 500mm or 1000mm lengths. Measure and mark exactly **284 mm**.
2. **Prevent Splintering**: Wrap a strip of blue painter's tape tightly around the cut line.
3. **Cutting**: Use a rotary tool (Dremel) with a thin abrasive diamond or fiberglass cut-off wheel. Cut at medium speed while wearing an N95/FFP2 dust mask.
4. **Deburring**: Lightly chamfer the outer edge using 320-grit sandpaper so the tube slides smoothly into the 3D-printed channels without catching.

---

## 2. Fasteners, Screws & Mechanical BOM

All hardware on Urumi uses standard metric fastener sizes.

| Component / Subsystem | Fastener Type & Dimensions | Quantity | Material & Specification | Function |
| :--- | :--- | :---: | :--- | :--- |
| **Motor Mounting** | **M3 × 6 mm or 8 mm** Socket/Button Head | **16x** | Grade 10.9/12.9 Steel or Stainless | Secures 4x brushless motors to `Motor mount 1-4` (4 screws per motor). Must use Blue Loctite! |
| **Central Avionics Stack** | **M3 × 20 mm or 25 mm** Pan/Socket Head | **4x** | Steel / Stainless | Secures 4-in-1 ESC and Flight Controller onto `FC Plate`. |
| **Avionics Standoffs** | **M3 Nylon Standoffs (5mm–6mm)** | **8x** | M3 Nylon | Spacing between ESC and Flight Controller to prevent shorts and heat transfer. |
| **Stack Nuts** | **M3 Nyloc Nuts** | **4x** | Nylon-insert locking nuts | Locks the top of the FC stack screws against vibration. |
| **Tilt Servo Mounting** | **M2 × 8 mm** Pan Head (or Self-tapping) | **2x** | Steel | Secures the 9g metal-gear servo into `Servo Plate` (27.6mm screw spacing). |
| **FPV Camera Cage** | **M2 × 4 mm or 6 mm** Socket Head | **4x** | Stainless Steel | Secures camera side brackets into `Camera mount` (20.2mm bracket width). |
| **Battery Retention** | **20 mm × 200 mm or 250 mm Strap** | **1x** | Rubberized non-slip Velcro | Retains 4S/6S LiPo or 4S 21700 pack on `Battery Plate`. |
| **Battery Pad** | **Adhesive Silicone / Foam Pad** | **1x** | 2mm–3mm thickness | Placed on `Battery Plate` to eliminate battery sliding during vertical takeoff. |
| **Anti-Vibration Dampers**| **M3 Silicone Rubber Bobbins** | **4x** | Molded silicone grommets | Isolates flight controller gyros from motor vibrations. |

---

## 3. Adhesives, Chemicals & Assembly Consumables

* **Cyanoacrylate (Medium CA Glue)**:
  * *Recommended*: **Bob Smith Industries Insta-Cure+** or **Gorilla Super Glue (Blue Cap)**.
  * *Role*: Joining fuselage mating bulkheads (`Fuselage 1-4`). Medium viscosity fills minor layer gaps and provides strong shear bonding on PLA.
* **CA Accelerator / Activator Spray**:
  * *Recommended*: **Bob Smith Industries Insta-Set**.
  * *Role*: Instantly cures CA glue within 2 seconds. Apply glue to one side, assemble, and mist the joint with activator.
* **Threadlocker (Blue Loctite 242)**:
  * *Role*: Medium-strength, removable anaerobic threadlocker.
  * ⚠️ **Mandatory**: Apply one small drop to every M3 motor screw. Motor vibration will loosen untreated screws within 2–3 flights.
* **Epoxy (Optional 5-Minute Epoxy)**:
  * Useful for bonding carbon tubes inside `Fuselage 2` and `Fuselage 3` if additional rigidity is desired.

---

## 4. 3D-Printed Parts Breakdown & Modular Locking System

### 4.1 Airframe Components Summary

| Subsystem | Included Files | Target Filament | Notes & Function |
| :--- | :--- | :--- | :--- |
| **Fuselage Core** | `Fuselage 1.3mf` (Nose)<br>`Fuselage 2.3mf`<br>`Fuselage 3.3mf`<br>`Fuselage 4.3mf` (Tail) | **PLA+ / PLA Basic** | Glued together with CA glue. Contains internal channels for 6mm carbon spars and gear bays. |
| **Aerofoil Wings** | `Wing 1-2.3mf` (Top Wings)<br>`Wing 3-4.3mf` (Bottom Wings) | **PLA+ / PLA Basic** | 4 wings angled at 22°. Mirrored left-to-right in slicer. Slide directly onto carbon spars. |
| **Propulsion Nacelles**| `Nacelle 1-2.3mf`<br>`Nacelle 3-4.3mf` | **PLA+ / PETG** | Aerodynamic nacelles at wingtips; house motor wiring. |
| **Motor Mounts** | `Motor mount 1-2-3-4.3mf` | **PLA+ (100% Solid)** | **Must be printed with 100% infill** for motor torque handling. |
| **Landing Feet** | `Pad 1.3mf`, `Pad 2.3mf`<br>`Pad 3.3mf`, `Pad 4.3mf` | **PLA+ / PETG** | Snap onto the bottom of each nacelle to absorb landing impact. |
| **Internal Plates** | `Battery Plate.3mf`<br>`FC Plate.3mf`<br>`Servo Plate.3mf`<br>`Camera mount.3mf` | **PLA+ / PLA Basic** | Internal structural gear trays for electronics and camera tilt. |
| **Access Canopies** | `Canopy 1.3mf`<br>`Canopy 2.3mf`<br>`Canopy locks.3mf` | **Foaming LW-PLA / ASA-Aero** (or PLA Basic) | Quick-release battery hatch and maintenance canopy. |

### 4.2 Glueless Removable Wing Locking Mechanism
Unlike earlier prototypes where wings had to be glued permanently to the fuselage, this version uses a **modular glueless slide-lock system**:
1. The wings slide freely over the 6.0mm carbon fiber spars.
2. The root of each wing slips into a recessed alignment socket in the fuselage.
3. The outer motor mounts (`Motor mount 1-4`) act as the retention stop: once bolted into place, they trap the wing securely between the fuselage and the motor nacelle.
4. **Crash Repair Advantage**: If a wing is cracked in a rough landing, simply unbolt the outer motor mount, slide off the broken wing, slide on a fresh 3D-printed spare, and re-tighten.

### 4.3 Alternate Tolerance Parts (`3D_Print_Files/Extras/`)
* **`Motor mount 1-2-3-4.tighter by 05mm.3mf`**:
  * Features a **0.05 mm tighter inner bore** on the carbon spar hole.
  * **When to use**: If your carbon fiber tubes measure slightly under 6.0mm (e.g. 5.92mm), or if you print in ABS (which shrinks by 1%–1.5%), test this tighter version to ensure zero slop on the spar.

---

## 5. Filament Selection & Mechanical Analysis

### 5.1 The Lightweight Filament Reality
* **558 grams out of 571 grams total plastic (97.7%) is printed in standard PLA / PLA+!**
* **Only the two small canopies (`Canopy 1` = 8g and `Canopy 2` = 5g, total 13g) were originally sliced for Foaming LW-PLA.**

```mermaid
pie title Urumi Printed Plastic Distribution (571g Total)
    "PLA+ / PLA Basic (Wings, Fuselage, Mounts, Plates)" : 558
    "Aero ASA / LW-PLA (Canopies 1 & 2 Only)" : 13
```

### 5.2 Mechanical Evaluation for Bambu Lab P1S

| Filament | Suitability | Tensile & Torsional Rigidity | Recommended Use Case |
| :--- | :--- | :--- | :--- |
| **Bambu PLA Basic / PLA+** | ⭐ **Recommended (Primary)** | **Very High** (Stiff, high dimensional accuracy) | **All structural parts**: Fuselage, wings, motor mounts, landing pads, and plates. Can also print canopies (adds only ~8g). |
| **ASA-Aero** | ✅ **Optional (Selective)** | **Low** (Foaming micro-cellular structure) | **Canopy 1 & Canopy 2 ONLY**. ⚠️ Never use for motor mounts or wing locking joints (insufficient shear strength). |
| **ABS** | ⚠️ **Advanced Option** | **High** (~16% lighter than PLA, heat resistant) | Fuselage & wings for enclosed P1S printers. Watch for 1%–1.5% shrinkage on 6.0mm carbon spar holes. |
| **PETG** | 🟢 **Alternative** | **Medium-High** (Excellent impact resistance) | Ideal for `Nacelle 1-4` and `Pad 1-4` to handle rough grass landings without snapping. |
| **PLA Silk+** | ❌ **DO NOT USE** | **Poor** (Weak inter-layer bonding) | **Never use for structural aircraft parts**. Delaminates under flight aerodynamic loads. |

---

## 6. Workshop Tools & Assembly Equipment List

* **Hex Screwdrivers**: 1.5 mm (for M2 screws), 2.0 mm (for M3 screws), and 2.5 mm.
* **Rotary Tool (Dremel)**: With fiberglass cut-off wheel for cutting carbon fiber tubing.
* **6.0 mm Round File / Drill Bit**: For gently clearing carbon spar channels if tight.
* **Digital Calipers**: For measuring carbon spar OD and checking airframe symmetry.
* **Soldering Station**: 60W–80W iron with chisel tip, 60/40 rosin-core solder, flux pen, and heat-shrink tubing.
* **Digital Gram Scale**: For verifying part print weights against the master table in [`docs/03_PRINT_GUIDE_AND_PROFILES.md`](03_PRINT_GUIDE_AND_PROFILES.md).

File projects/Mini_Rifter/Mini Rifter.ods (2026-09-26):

 | Mini Rifter
Part | Profile | Infill % | Time (P1P) | Grams | Modifiers
Wing L 1 | A | 4 gyro | 01:12 | 24
Wing R 1 | A | 4 gyro | 01:12 | 24
Wing L 2 | A | 4 gyro | 03:19 | 43 | +support
Wing R 2 | A | 4 gyro | 03:19 | 43 | +support
Wing L+R aileron 1 | A | 6 gyro | 00:27 | 10 | 15 bottom layers
Wing L+R aileron 2 | A | 6 gyro | 00:27 | 10
Motor mount | C | 100 | 00:08 | 5 | Align to plate, not 90° !
Fuselage 1 | C | 0 | 00:21 | 7
Fuselage 2 | C | 100 | 00:05 | 2
Fuselage 3 | A | 6 gyro | 02:42 | 35
Fuselage 4 | A | 6 gyro | 03:05 | 46
Stab L | B | 6 gyro | 00:25 | 13 | 2 bottom, 2 top
Stab R | B | 6 gyro | 00:25 | 13 | 2 bottom, 2 top
Batterie plate | C | 10 gyro | 00:19 | 10 | 3 bottom, 3 top
Canopy R | C LW | 10 gyro | 00:29 | 6 | 2 bottom, 2 top, 4 walls
Canopy F | C LW | 10 gyro | 00:25 | 5 | 2 bottom, 2 top, 4 walls
Canopy locks | C | 0 | 00:14 | 4
Wing lock L + R | C | 0 | 00:34 | 13 | 4 walls +support
Hinges (TPU) | B | 100 | 00:10 | 1 | TPU / flexible plastic
 | Total : |  | 19:18 | 314
Profile | Layer hei. | Walls | Top, bottom
A | 0,20 | 1 | 3 | PLA+
B | 0,20 | 2 | 4
C | 0,20 | 3 | 5
A LW | 0,2 | 1 | 3 | Esun / 3DLP Foaming PLA-LW 250°C flow 0.50
B LW | 0,2 | 2 | 4
C LW | 0,2 | 3 | 5
Carbon tubes : Front wing spar : 6x600mm Rear wing spar : 6x260mm

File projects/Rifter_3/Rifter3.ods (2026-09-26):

 | Print 1 |  |  |  |  | Print 2
Part | Profile | Infill % | Time (P1P) | Grams | Modifiers | Profile | Infill % | Time (P1P) | Grams | Modifiers
Wing L 1 | A | 6 gyro | 00:34 | 11 |  | B PMLW | 6 gyro | 00:46 | 12
Wing R 1 | A | 6 gyro | 00:34 | 11 |  | B PMLW | 6 gyro | 00:46 | 12
Wing L 2 |  |  |  |  |  | A PMLW | 4 gyro | 02:33 | 36
Wing R 2 |  |  |  |  |  | A PMLW | 4 gyro | 02:33 | 36
Wing L 3 |  |  |  |  |  | A PMLW | 4 gyro | 03:19 | 47
Wing R 3 |  |  |  |  |  | A PMLW | 4 gyro | 03:19 | 47
Wing L 4 | B LW | 6 gyro | 01:26 | 20 |  | B LW | 6 gyro | 01:26 | 20
Wing R 4 | B LW | 6 gyro | 01:26 | 20 |  | B LW | 6 gyro | 01:26 | 20
Wing L aileron | A | 6 gyro | 01:48 | 12 | 12 bottom layers | A | 6 gyro | 01:48 | 12 | 12 bottom layers
Wing R aileron | A | 6 gyro | 01:48 | 12 | 12 bottom layers | A | 6 gyro | 01:48 | 12 | 12 bottom layers
Stab L | A LW | 7 gyro | 01:04 | 14 |  | A LW | 7 gyro | 00:51 | 12
Stab R | A LW | 7 gyro | 01:04 | 14 |  | A LW | 7 gyro | 00:51 | 12
Fuselage 1 | B | 0 | 00:38 | 17 |  | C PMLW | 0 | 00:52 | 14,5
Fuselage 2 | B | 100 | 00:10 | 4 |  | C PMLW | 100 | 00:13 | 3,5
Fuselage 3 | A | 4 gyro | 02:41 | 37 |  | A PMLW | 7 gyro | 02:25 | 33
Fuselage 4 | A | 4 gyro | 02:50 | 42 |  | A PMLW | 7 gyro | 02:52 | 39
Fuselage 5 | B | 0 | 00:25 | 6,5 |  | C PMLW | 0 | 00:25 | 7
Canopy | A | 4 gyro | 02:03 | 20 |  | A | 4 gyro | 02:03 | 20
Hatch | B | 10 gyro | 00:20 | 10 | 2 bottom, 2 top layers | B | 10 gyro | 00:20 | 10 | 2 bottom, 2 top layers
Batterie plate | B | 10 gyro | 00:16 | 9 |  | B PMLW | 15 gyro | 00:24 | 7
Motor mount | B | 100 | 00:12 | 3,5 |  | D | 100 | 00:12 | 3,5
Canopy lock |  |  |  |  |  | D |  |  | 4
Wing lock L+R | B | 100 | 00:18 | 8,5 |  | D | 100 | 00:18 | 8,5
Hinges (TPU) | B | 100 | 00:10 | 2 |  | D | 100 | 00:10 | 2
 | Total : |  | - | - |  | Total : |  | 31:40 | 430
Profile | Layer hei. | Walls | Top, bottom
A | 0,20 | 1 | 3 | PLA+
B | 0,20 | 2 | 4
C | 0,20 | 3 | 5
A LW | 0,2 | 1 | 3 | Esun / 3DLP Foaming PLA-LW 250°C flow 0.50
B LW | 0,2 | 2 | 4
C LW | 0,2 | 3 | 5
A PMLW | 0,2 | 1 | 3 | Polymaker Polylite Pre-foamed
B PMLW | 0,2 | 2 | 4
C PMLW | 0,2 | 3 | 5
Carbon tubes : Front wing spar : 8x800mm Rear wing spar : 6x400mm 2x fuselage sides (optional) : 6x135mm

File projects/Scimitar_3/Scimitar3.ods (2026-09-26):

 | Scimitar 3
Part | Profile | Infill % | Time (P1P) | Grams | Modifiers
Wing L 1 | A | 4 gyro | 00:49 | 20
Wing R 1 | A | 4 gyro | 00:49 | 20
Wing L 2 | A | 5 gyro | 02:59 | 53 | +support
Wing R 2 | A | 5 gyro | 02:59 | 53 | +support
Wing L 3 | A | 5 gyro | 00:54 | 21
Wing R 3 | A | 5 gyro | 00:54 | 21
Wing ailerons | A | 6 gyro | 01:38 | 21 | 12 bottom layers
Wing lock L+R | C | 100 | 00:35 | 15 | 5 walls
Fuselage 1 SCM | B | 0 | 00:44 | 19
Fuselage 2 | A | 4 gyro | 03:06 | 73
Fuselage 3 | A | 4 gyro | 03:09 | 80
Motor mount | C | 100 | 00:10 | 3
FC+batterie plates | C | 10 gyro | 00:40 | 18 | 3 bottom, 3 top
Canopy locks | C | 0 | 00:14 | 4
Canopy F+R | C LW | 10 gyro | 01:12 | 16 | 2 bottom, 2 top, 4 walls
Hinges (TPU) | B | 100 | 00:10 | 1 | TPU
 | Total : |  | 21:02 | 438
Profile | Layer hei. | Walls | Top, bottom
A | 0,20 | 1 | 3 | PLA+ PLA+CF
B | 0,20 | 2 | 4
C | 0,20 | 3 | 5
A LW | 0,2 | 1 | 3 | Esun / 3DLP Foaming PLA-LW 250°C flow 0.50
B LW | 0,2 | 2 | 4
C LW | 0,2 | 3 | 5
Carbon tubes : Main wing spar : 8x750mm Front wing spars : 6x150mm (x2)

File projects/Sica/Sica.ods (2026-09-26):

 | Sica
Part | Profile | Infill % | Time (P1P) | Grams | Modifiers
Wing L 1 | A | 3 gyro | 02:09:00 | 49 | +support
Wing R 1 | A | 3 gyro | 02:35:00 | 57 | +support
Wing L 2 | A | 3 gyro | 02:09:00 | 49 | +support
Wing R 2 | A | 3 gyro | 02:35:00 | 57 | +support
Wing L 3 | A | 3 gyro | 03:29 | 57
Wing R 3 | A | 3 gyro | 03:29 | 57
Wing L 4 | A | 6 gyro | 00:50 | 12
Wing R 4 | A | 6 gyro | 00:50 | 12
Wing L+R ailerons 1+2 | A | 6 gyro | 01:51 | 23 | 13 bottom layers
Nacelle L | C | 6 gyro | 00:49 | 33
Nacelle R | C | 6 gyro | 00:49 | 33
Motor mount L+R | C | 100 | 01:07 | 34
Fuselage 1 | C | 0 | 00:38 | 14
Fuselage 2 | C | 100 | 00:09 | 4
Fuselage 3 | A | 6 gyro | 02:14 | 31
Fuselage 4 | A | 6 gyro | 02:25 | 40
Fuselage 5 | A | 6 gyro | 02:17 | 26
Stab 1 | A | 3 gyro | 01:13 | 22 | +support
Stab 2L + 2R | B | 3 gyro | 00:53 | 33 | +support
Rudder L | A | 6 gyro | 01:45 | 14
Rudder R (same as L) | A | 6 gyro | 01:45 | 14
Elevator L + R | A | 5 gyro | 01:58 | 15 | 13 bottom layers
Batterie plate | C | 10 gyro | 00:21 | 11 | 3 bottom, 3 top
Canopy front | C | 6 gyro | 00:25 | 13 | 2 bottom, 2 top, 5 walls
Canopy rear | C | 6 gyro | 00:18 | 8 | 2 bottom, 2 top, 5 walls
Canopy handle | B | 100 | 00:05 | 1 | Quantity: 2
Wing lock L+R | C | 10 gyro | 00:41 | 26 | 5 walls
Hinges (TPU) | B | 100 | 00:10 | 1 | TPU / flexible plastic
 | Total : |  | 39:59 | 746
Profile | Layer hei. | Walls | Top, bottom
A | 0,20 | 1 | 3 | PLA+
B | 0,20 | 2 | 4
C | 0,20 | 3 | 5
A LW | 0,2 | 1 | 3 | Esun / 3DLP Foaming PLA-LW 250°C flow 0.50
B LW | 0,2 | 2 | 4
C LW | 0,2 | 3 | 5
Carbon tubes : Front wing spar : 8x1000mm (can be shortened down to 800mm) Rear wing spar : 6x700mm Stab tubes (2x) : 8x330mm

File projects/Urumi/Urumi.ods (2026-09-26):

 | Urumi (X-wing)
Part | Profile | Infill % | Time (P1P) | Grams | Modifiers
Nacelle 1+2+3+4 | B | 0 | 02:04 | 60 | 1+2 identical, 3+4 identical. +Support
Motor mount 1+2+3+4 | C | 100 | 01:09 | 48 | All 4 identical
Pads 1+2+3+4 | C | 0 | 00:58 | 29 | All 4 different
Wing 1 | A | 3 gyro | 03:10 | 58 | 1+2 identical, 3+4 identical
Wing 2 | A | 3 gyro | 03:10 | 58 | 1+2 identical, 3+4 identical
Wing 3 | A | 3 gyro | 03:10 | 58 | 1+2 identical, 3+4 identical
Wing 4 | A | 3 gyro | 03:10 | 58 | 1+2 identical, 3+4 identical
Fuselage 1 | B | 0 | 00:47 | 18
Fuselage 2 | A | 4 gyro | 03:02 | 58 | 8 top layers
Fuselage 3 | C | 0 | 01:01 | 35
Fuselage 4 | A | 5 gyro | 02:55 | 53
Canopy 1 | C LW | 10 gyro | 00:32 | 8 | 2 bottom layers, 2 top layers, 4 walls
Canopy 2 | C LW | 10 gyro | 00:24 | 5 | 2 bottom layers, 2 top layers, 4 walls
Canopy locks | C | 0 | 00:14 | 4
Battery plate | A | 8 gyro | 00:19 | 11 | 3 walls
FC plate | A | 8 gyro | 00:15 | 5 | 3 walls
Servo plate | A | 8 gyro | 00:10 | 5 | 3 walls
Camera mount | C | 0 | 00:36 | 8 | +Support
 | Total : |  | 26:30 | 571
Profile | Layer hei. | Walls | Top, bottom
A | 0,20 | 1 | 3 | PLA+
B | 0,20 | 2 | 4
C | 0,20 | 3 | 5
A LW | 0,2 | 1 | 3 | Esun / 3DLP Foaming PLA-LW 250°C flow 0.50
B LW | 0,2 | 2 | 4
C LW | 0,2 | 3 | 5
Carbon tubes : 6x284mm (x4)

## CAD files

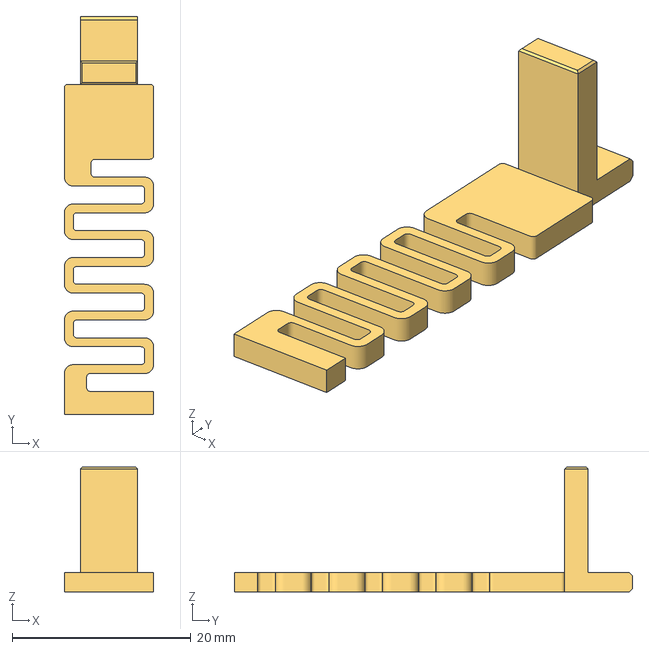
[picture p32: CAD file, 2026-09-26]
projects/Common/3D_Print_Files/01_Canopy_Spring_Locks/Canopy spring Lock 1.3mf
10.0 x 44.6 x 14.0 mm

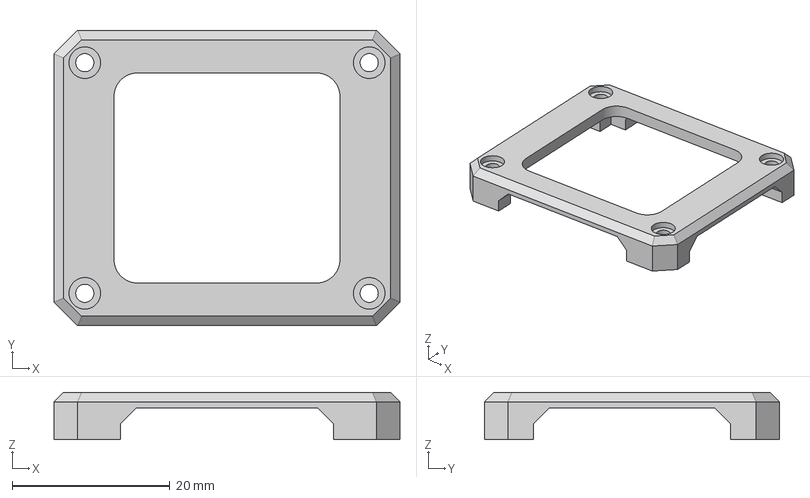
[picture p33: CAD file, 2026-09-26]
projects/Common/3D_Print_Files/02_DJI_O3_Mounts/DJI O3 cage 2.3mf
43.8 x 37.4 x 6.00 mm

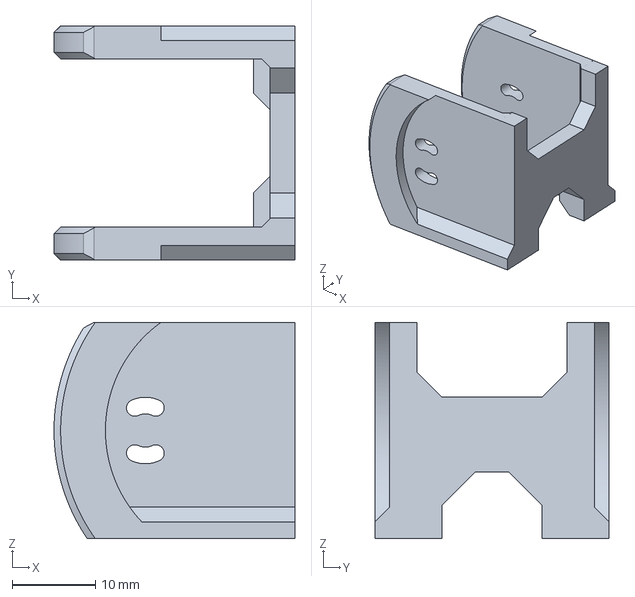
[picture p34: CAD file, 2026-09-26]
projects/Common/3D_Print_Files/03_Standard_Camera_Mounts_SCM/DJI O3 Cam mount.3mf
29.0 x 28.2 x 26.0 mm

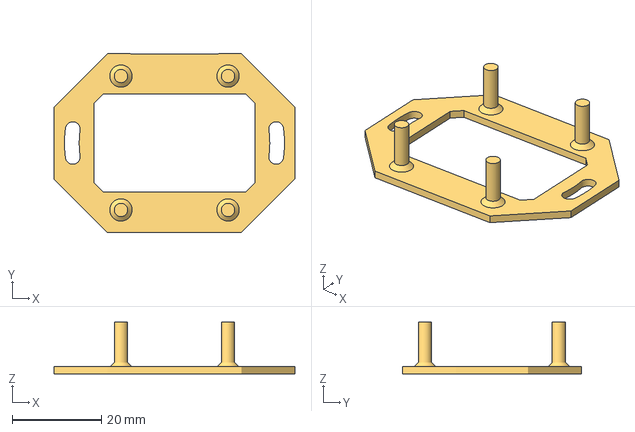
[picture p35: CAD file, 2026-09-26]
projects/Common/3D_Print_Files/04_Universal_FC_Plates_and_Hardware/FC plate 4 24x30.3mf
54.0 x 40.0 x 11.6 mm

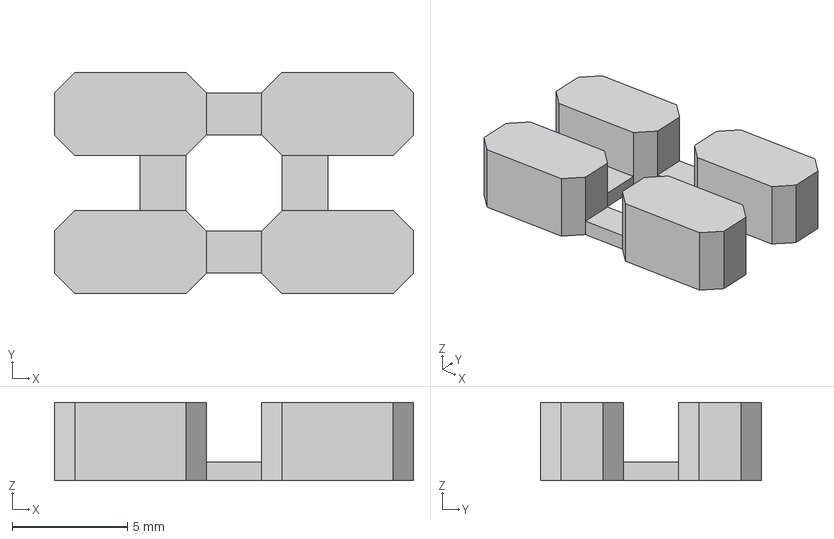
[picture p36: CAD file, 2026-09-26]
projects/Mini_Rifter/3D_Print_Files/01_Fuselage/F3F4 pins.3mf
15.6 x 9.60 x 3.40 mm

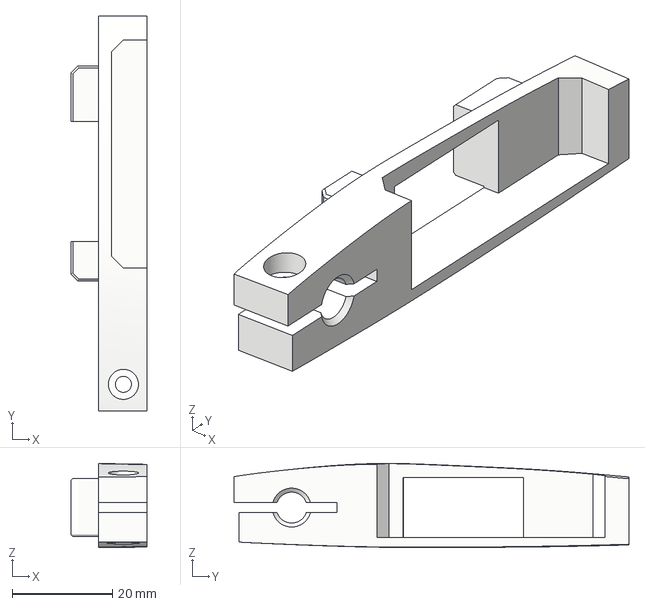
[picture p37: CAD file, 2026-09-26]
projects/Mini_Rifter/3D_Print_Files/02_Wings/Wing L Lock.3mf
15.3 x 78.7 x 16.8 mm

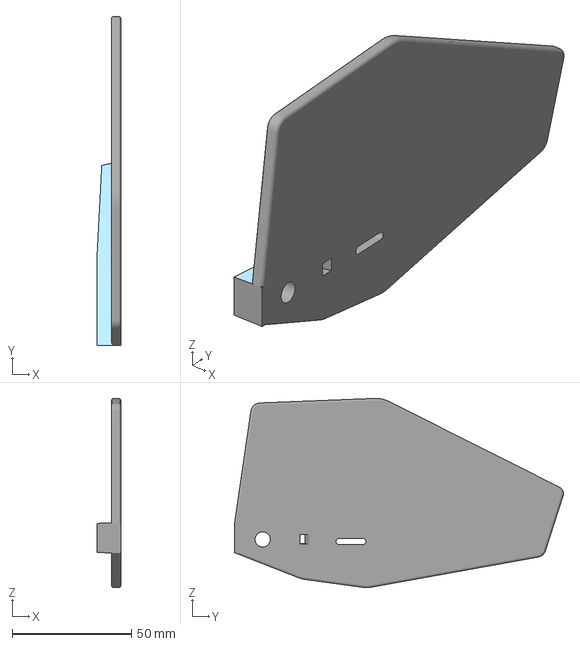
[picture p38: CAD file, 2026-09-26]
projects/Mini_Rifter/3D_Print_Files/03_Tail_and_Stabs/Wing R Stab.3mf
10.0 x 137.9 x 79.3 mm

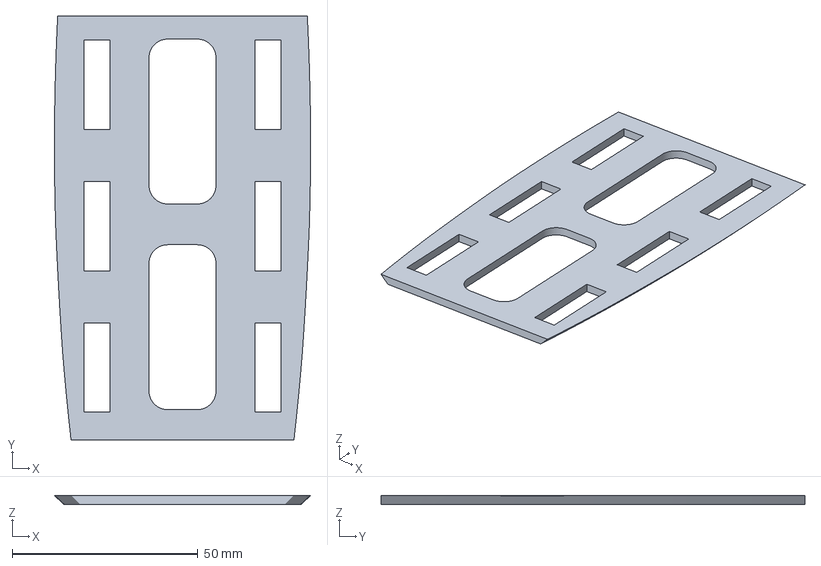
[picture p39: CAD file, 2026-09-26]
projects/Mini_Rifter/3D_Print_Files/04_Internal_Plates/Battery plate.3mf
68.9 x 114.0 x 2.40 mm

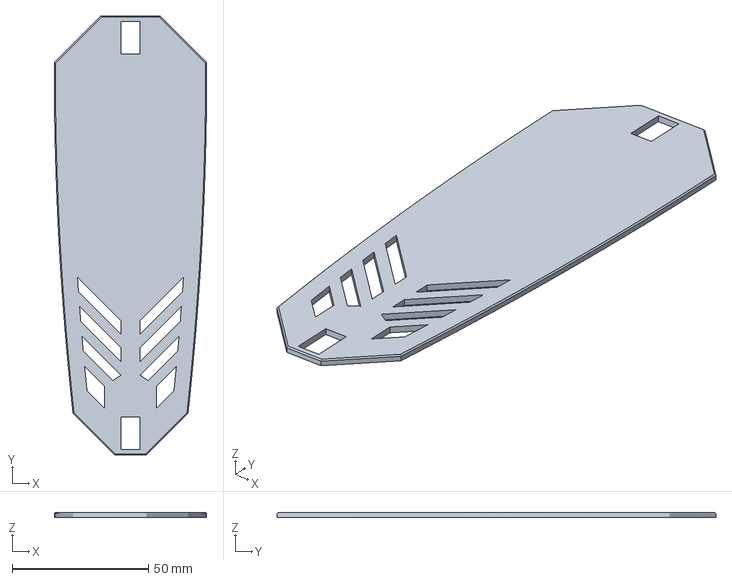
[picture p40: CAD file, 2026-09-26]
projects/Mini_Rifter/3D_Print_Files/05_Canopy/Canopy F.3mf
55.9 x 161.0 x 1.80 mm

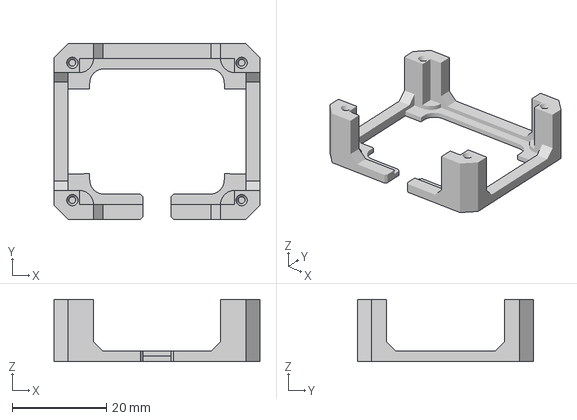
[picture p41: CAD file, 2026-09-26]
projects/Mini_Rifter/3D_Print_Files/Extras/DJI O3 AU outside/DJI O3 cage 1.3mf
43.8 x 37.4 x 13.2 mm

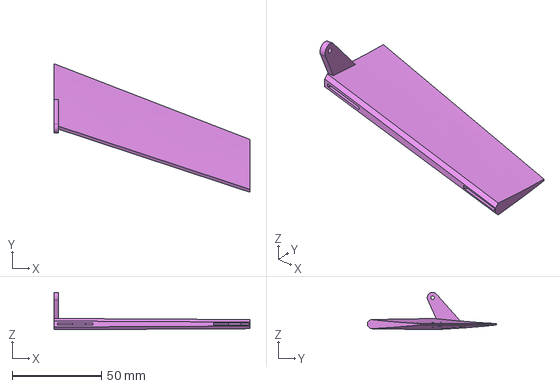
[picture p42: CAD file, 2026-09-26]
projects/Mini_Rifter/CAD_Source_STEP/Wing L Aileron 1.step
110.0 x 72.2 x 21.0 mm

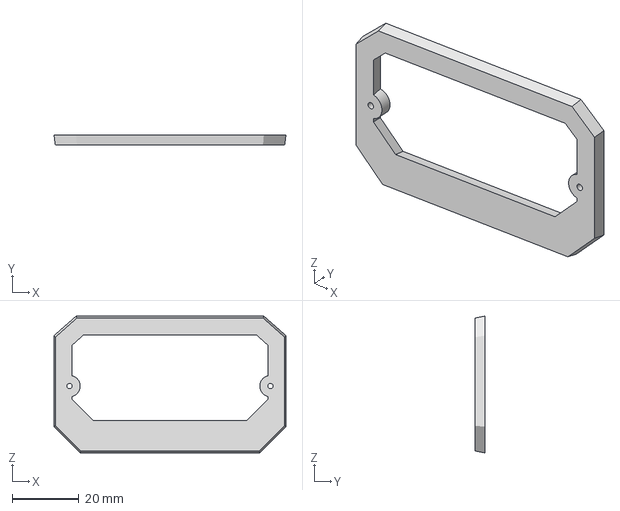
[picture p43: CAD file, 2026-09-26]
projects/Rifter_3/3D_Print_Files/01_Fuselage/Fuselage 2.3mf
69.5 x 3.00 x 41.0 mm

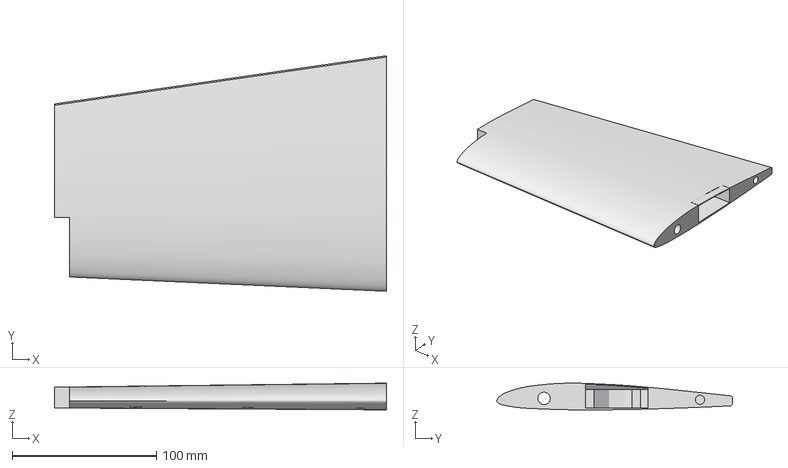
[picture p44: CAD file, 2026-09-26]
projects/Rifter_3/3D_Print_Files/02_Wings/Wing right 3.3mf
230.0 x 163.2 x 18.5 mm

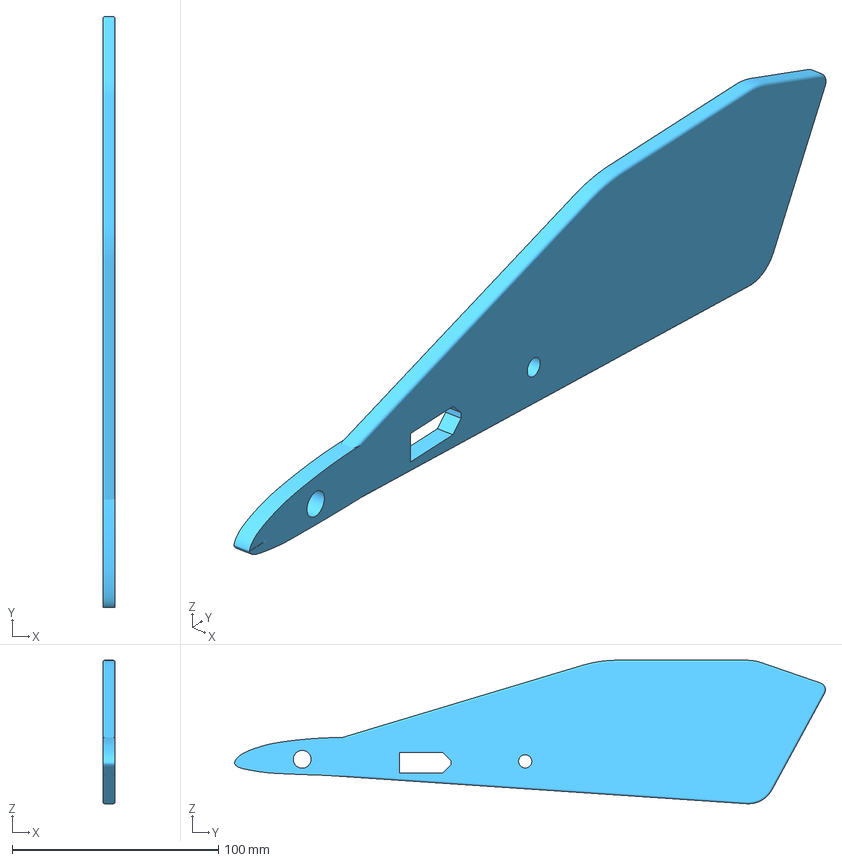
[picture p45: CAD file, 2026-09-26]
projects/Rifter_3/3D_Print_Files/03_Tail_and_Stabs/Stab LR.3mf
6.00 x 286.2 x 69.6 mm

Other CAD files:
projects/Mini_Rifter/3D_Print_Files/Extras/Wing L Stab RIFTERMINI.3mf
projects/Rifter_3/3D_Print_Files/04_Internal_Plates/Battery plate.3mf
projects/Rifter_3/3D_Print_Files/05_Canopy/Canopy.3mf
projects/Rifter_3/3D_Print_Files/Extras/GPS plate.3mf
projects/Common/3D_Print_Files/01_Canopy_Spring_Locks/Canopy spring Lock 2.3mf
projects/Common/3D_Print_Files/02_DJI_O3_Mounts/DJI O3 VTX mount.3mf
projects/Common/3D_Print_Files/03_Standard_Camera_Mounts_SCM/HDZero Micro Cam mount.3mf
projects/Common/3D_Print_Files/03_Standard_Camera_Mounts_SCM/Walksnail Cam mount.3mf
projects/Common/3D_Print_Files/04_Universal_FC_Plates_and_Hardware/FC plate 1.3mf
projects/Common/3D_Print_Files/04_Universal_FC_Plates_and_Hardware/FC plate 2.3mf
projects/Common/3D_Print_Files/04_Universal_FC_Plates_and_Hardware/FC plate 3.3mf
projects/Common/3D_Print_Files/04_Universal_FC_Plates_and_Hardware/M3 knurl.3mf
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

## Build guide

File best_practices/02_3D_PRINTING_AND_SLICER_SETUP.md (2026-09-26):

# 🖨️ Guide 02: 3D Printing & Slicer Setup




Unlike conventional 3D-printed aircraft that rely on complex spiral vase mode or fragile single-wall internal rib models, the **AeroBlades** fleet by Olivier_C uses a unique, robust construction methodology: **thin exterior walls reinforced by a continuous 3D Gyroid infill truss core**.

This guide details the precise slicer settings, orientation strategies, and dimensional compensation techniques required to print perfect, warp-free airframes.

---

## 1. The Olivier_C Thin-Wall Gyroid Philosophy

Most aircraft STL files in this repository are solid or hollow geometries designed to be sliced with specific perimeter and infill combinations:

```mermaid
graph TD
    SHELL["<b>Outer Aerodynamic Shell</b><br/>1–2 Smooth Perimeters (PLA+ / Tough PLA)"]
    CORE["<b>Internal 3D Gyroid Core</b><br/>3% – 6% Isotropic Truss Infill (Torsional Resistance)"]
    SPAR["<b>Continuous Carbon Fiber Spine</b><br/>6.0mm / 8.0mm Pultruded Carbon Tube (Bending Load)"]

    SHELL --- CORE
    CORE --- SPAR
```

### Why Gyroid Infill?
* **Isotropic Strength**: Unlike rectilinear or grid infill (which only support forces in X/Y planes), Gyroid is a 3D triply periodic minimal surface that provides uniform resistance against bending, torsional twisting, and shear loads in all 3 axes.
* **Continuous Airflow & Wire Pass-Through**: The curved channels of gyroid infill allow internal servo cables and antenna leads to be fished through wings without needing pre-cut wiring tunnels.
* **Lightweight Efficiency**: At only 3% to 6% density, gyroid adds massive torsional rigidity to thin wings while adding only a few grams of weight.

---

## 2. Master Slicing Profiles Cheat Sheet

All models in the fleet are tuned for **0.4mm nozzles** and **0.20mm layer heights** in **Bambu Studio**, **OrcaSlicer**, or **PrusaSlicer**:

| Profile Code | Profile Name | Perimeters (Walls) | Top / Bottom Layers | Infill % & Pattern | Typical Weight/Speed Balance | Typical Use Cases |
| :---: | :--- | :---: | :---: | :---: | :--- | :--- |
| **Profile A** | Thin / Aero | 1 | 3 / 3 | 3% – 6% Gyroid | Maximum lightness, high surface fidelity | Wing panels, elevons, ailerons, main fuselage cabins |
| **Profile B** | Medium | 2 | 4 / 4 | 0% – 10% Gyroid | Balanced strength & impact resistance | Nose bays, tail cones, winglets, vertical stabs |
| **Profile C** | Heavy Structural | 3 – 4 | 5 / 5 | 0% or 10% Gyroid | Maximum rigidity, solid hard points | Landing pads, wing locks, battery trays, camera brackets |
| **Profile D** | Solid Retention | 4 – 5 | 5 / 5 | 100% Rectilinear | Extreme shear & thread grip strength | Motor mounts, servo brackets, alignment pins |
| **Profile LW**| Active Foaming | 1 – 2 | 2 / 2 | 8% – 10% Gyroid | Ultra-lightweight (0.55–0.65 density) | Aerodynamic canopies, sun covers, non-structural fairings |
| **TPU** | Flexible Hinge | 2 – 3 | 4 / 4 | 100% Solid | Flexible elastic live hinge | Wing control surface hinges (95A TPU) |

---

## 3. Dimensional Tolerances & Carbon Spar Channels

All airframes in this fleet incorporate longitudinal hollow channels designed for **6.0 mm** and **8.0 mm** outer diameter (OD) pultruded carbon fiber tubes.

### The Problem: Hole Undersizing
Due to plastic thermal shrinkage and 3D printing inner-hole polygon faceting, printed holes are virtually always **0.1mm to 0.25mm smaller** than their nominal CAD dimensions. If not compensated, carbon spars will bind or crack the wing root during insertion.

### Recommended Slicer Settings:
1. **X-Y Hole Compensation (OrcaSlicer / Bambu Studio)**:
   * Set **X-Y Hole Compensation**: `+0.10 mm` to `+0.15 mm`.
   * Leave **X-Y Contour Compensation**: `0.0 mm` (maintains true outer aerodynamic airfoil profile).
2. **ASA / ABS Shrinkage Factor**:
   * If printing with ASA or ABS, apply an overall X/Y scale compensation of **100.8% to 101.2%**.
3. **Manual Workshop Reaming**:
   * Always have a standard 6.0mm or 8.0mm round file or metal drill bit on hand.
   * Slide the carbon spar into each segment dry *before* applying adhesive. The spar should slide through with light thumb pressure—never force a spar with a hammer.

---

## 4. Bed Adhesion & Orientation Best Practices

Many fuselage and wing segments stand **180mm to 240mm tall** on the build plate with a relatively narrow footprint. Preventing mid-print detachment or corner warping is paramount:

### 1. Build Plate Preparation
* **Textured PEI Plate**: Strongly recommended for PLA+, PETG, and ASA. Wash thoroughly with hot water and dish soap (Dawn / Fairy) to remove finger oils. Do not rely solely on Isopropyl Alcohol (IPA), which merely spreads grease.
* **Brim Configuration**:
  * For tall, slender wing panels: Enable an **Outer Brim of 5 mm – 10 mm** with a **0.1 mm Brim-Object Gap** for clean removal.
  * For flat-bottom fuselage parts: Brim can usually be disabled if bed leveling is properly calibrated.

### 2. Seam Placement Strategy
* Never use *Random* seam placement on aerodynamic surfaces—it creates hundreds of tiny drag-inducing pimples across the wing airfoil.
* Set **Seam Position**: **Aligned** or **Rear**.
* Position the seam along the **trailing edge** of the wing or inside the fuselage lock recess where airflow disturbance is minimized.

### 3. Cooling Fan Management
* **PLA+**: Set part cooling fan to **50%–70%**. Avoid blasting 100% fan on 1-perimeter wing shells, as rapid chilling reduces inter-layer fusion strength.
* **ASA / ABS**: Cooling fan **10%–20% maximum**, enclosed chamber at 45°C+.
* **PETG**: Cooling fan **20%–40%** to avoid brittle inter-layer bonding.

---

## 5. Post-Processing & Airframe Bonding

* **Cyanoacrylate (CA Glue) + Accelerator**:
  * Medium-viscosity CA glue (e.g., Gorilla Super Glue, BSI Insta-Cure+) is the gold standard for PLA+ and PETG aircraft assembly.
  * Lightly scuff bonding mating surfaces with 240-grit sandpaper before gluing.
  * Use aerosol activator sparingly to set alignment pins instantly.
* **Polyurethane / Epoxy for Spars**:
  * For permanently bonded carbon spars, use **5-minute or 15-minute 2-part epoxy**. Epoxy fills micro-voids between the round spar and printed internal ribs without melting the plastic.

---

## 6. 📚 Authoritative References & Citations

1. **Bambu Lab / OrcaSlicer Documentation**: *"X-Y Hole & Contour Compensation"* — Technical documentation on compensating for polymer shrinkage and inner perimeter facet contraction. [[OrcaSlicer Wiki](https://github.com/SoftFever/OrcaSlicer/wiki)]
2. **CNC Kitchen (Stefan Hermann)**: *"Carbon Fiber Tube Reinforcement in 3D-Printed Wings"* — Load deflection analysis showing how structural carbon tubes absorb bending loads while printed plastic handles airfoil shape. [[CNC Kitchen](https://www.cnckitchen.com/)]
3. **Prusa Research**: *"Print Quality & Seam Placement Guide"* — Managing alignment seams on aerodynamic curved shells to minimize drag. [[Prusa Knowledge Base](https://help.prusa3d.com/)]
4. **Olivier_C**: *"Rifter, Sabre, Scimitar CAD release logs"* — Origin of the 3%–6% Gyroid structural infill profile specifications. [[RCGroups Thread #4223695](https://www.rcgroups.com/forums/showthread.php?4223695-Rifter-Sabre-Scimitar-mini-sized-FPV-cruisers)]

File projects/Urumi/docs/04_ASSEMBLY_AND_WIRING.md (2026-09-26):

# 🛠️ Step-by-Step Airframe Assembly & Wiring Guide

> **Urumi VTOL Hybrid** combines a central fuselage with a rigid 4-point carbon-fiber X-frame, four angled wings (22°), four motor nacelles, and a servo-actuated tilting FPV camera.

---

## 1. Required Hardware, Consumables & Tools

### Structural & Fasteners
* **4x Carbon Fiber Tubes**: **6.0 mm Outer Diameter × 284 mm Length** (hollow pultruded tube, 4mm ID).
* **Medium Cyanoacrylate (CA Glue)** (e.g. *Bob Smith Insta-Cure+* or *Gorilla Super Glue*).
* **CA Accelerator / Activator Spray** (essential for rapid, strong bonding).
* **16x M3 × 6mm or 8mm socket screws**: For motor mounting.
* **4x M3 × 20mm screws & nylon standoffs/nuts**: For the FC / ESC central stack.
* **2x M2 × 8mm self-tapping screws**: For mounting the 9g tilt servo.
* **4x M2 × 4mm or 6mm screws**: For mounting the FPV camera (DJI O3/O4 or micro camera).
* **1x Non-slip Battery Strap**: 20mm × 200mm or 250mm.
* **Threadlocker (Blue Loctite 242)**: For all motor screws.

### Tools
* 1.5mm, 2.0mm, and 2.5mm hex screwdrivers.
* 6.0mm round file or drill bit (for cleaning out carbon tube channels if needed).
* Fine-grit sandpaper (240–400 grit) for smoothing mating bulkheads.
* Soldering iron (60W+) with 60/40 or lead-free solder and flux.

---

## 2. Airframe Assembly Sequence

```mermaid
flowchart LR
    S1["<b>Step 1: Fuselage & Spars</b><br/>Bond Fuselage 1-4 & insert 4× 6mm carbon spars"]
    S2["<b>Step 2: Internal Trays</b><br/>Install FC plate, battery plate & camera tilt servo"]
    S3["<b>Step 3: Modular Wings</b><br/>Slide Wings 1-4 onto spars with snap roots"]
    S4["<b>Step 4: Nacelles & Motors</b><br/>Mount motor nacelles, motors & landing pads"]
    S5["<b>Step 5: Wiring & Canopy</b><br/>Connect ESC/FC/DJI O3 & snap lock canopy"]

    S1 --> S2 --> S3 --> S4 --> S5
```

### Step 1: Fuselage Alignment & Carbon Spar Insertion
1. Gather the four printed fuselage sections: `Fuselage 1` (nose), `Fuselage 2`, `Fuselage 3`, and `Fuselage 4` (tail).
2. **Dry Fit the Carbon Tubes**:
   * Slide the four 6.0mm × 284mm carbon tubes through the X-frame channels in `Fuselage 2` and `Fuselage 3`.
   * Ensure each tube slides smoothly without forcing. If tight, gently run a 6.0mm drill bit or round file through the printed channels.
3. **Bonding the Fuselage**:
   * Apply medium CA glue to the mating flanges of `Fuselage 2` and `Fuselage 3`.
   * Press firmly together, ensuring the internal carbon tube alignment holes match perfectly.
   * Mist the seam with CA accelerator.
   * Join `Fuselage 1` (nose) and `Fuselage 4` (tail) in the same manner.

---

### Step 2: Internal Mounting Plates & Tilt Mechanism
1. **Flight Controller Plate (`FC Plate`)**:
   * Slide `FC Plate` into its dedicated internal fuselage slots.
   * Secure your 4-in-1 ESC and Flight Controller onto the vibration-damping silicone bobbins using M3 hardware. (Supports both 30.5×30.5mm and 20×20mm hole patterns).
2. **Battery Plate (`Battery Plate`)**:
   * Thread your 20mm battery strap through the bottom slots of `Battery Plate` before gluing or snapping it into the fuselage bay.
   * Add a strip of adhesive silicone or foam padding to prevent LiPo pack slippage.
3. **Tilt Servo Installation (`Servo Plate`)**:
   * Mount the 9g metal-gear servo (e.g., *EMAX ES08MA II*) into `Servo Plate` using 2x M2 screws.
   * Center the servo electrically using a servo tester or FC output (1500µs midpoint) before attaching the servo horn.
4. **Camera Tilt Mount (`Camera mount`)**:
   * Mount your FPV camera (DJI O3, DJI O4, or 19mm micro camera) into `Camera mount` using M2 screws.
   * Snap or pin the camera mount into the pivot brackets in `Fuselage 1`.
   * Connect a short pushrod or direct-drive link from the 9g servo horn to the camera mount arm.

---

### Step 3: Modular Removable Wing System
Urumi features a glueless, removable wing locking design:
1. Slide **Wing 1** (top left) and **Wing 2** (top right) onto the top carbon spars.
2. Slide **Wing 3** (bottom left) and **Wing 4** (bottom right) onto the bottom carbon spars.
3. Push each wing firmly until the root aerofoil locks into the fuselage recess.
4. The motor mounts and nacelles act as the outer wing retaining locks—preventing the wings from sliding off during flight.

---

### Step 4: Motor Mounts, Nacelles & Landing Pads
1. Slide `Motor mount 1-2-3-4` onto the outer tip of each carbon fiber spar.
   * *Note*: If the spar fit feels slightly loose, use `3D_Print_Files/Extras/Motor mount 1-2-3-4.tighter by 05mm.3mf`.
2. Secure the brushless motors to the mounts using 4x M3 screws per motor with blue Loctite.
3. Slide `Nacelle 1-2` and `Nacelle 3-4` into place over the wingtips and mounts.
4. Snap on `Pad 1`, `Pad 2`, `Pad 3`, and `Pad 4` onto the bottom of each nacelle to form the landing feet.

---

## 3. Full Electronics Wiring Diagram

```
                       +-----------------------------+
                       |    Flight Battery (4S-6S)   |
                       +--------------+--------------+
                                      | (XT60)
                                      v
+-------------------------------------+-------------------------------------+
|                     45A - 60A 4-in-1 ESC (Central Stack)                   |
|  [Motor 1 Out]         [Motor 2 Out]         [Motor 3 Out]        [Motor 4 Out]
+-------+---------------------+---------------------+---------------------+--+
        |                     |                     |                     |
        v (3 wires)           v (3 wires)           v (3 wires)           v (3 wires)
   +----+-----+          +----+-----+          +----+-----+          +----+-----+
   | Motor 1  |          | Motor 2  |          | Motor 3  |          | Motor 4  |
   | (Top L)  |          | (Top R)  |          | (Bot L)  |          | (Bot R)  |
   +----------+          +----------+          +----------+          +----------+

                                      | (VBAT + Current + Telemetry)
                                      v
+-------------------------------------+-------------------------------------+
|                      INAV Flight Controller (F405 / F722)                 |
|                                                                           |
|  • PWM S1-S4: ESC Motor Signals 1-4                                       |
|  • PWM S5   : Camera Tilt Servo Signal (EMAX ES08MA II)                   |
|  • UART1    : DJI O3 / O4 Air Unit (MSP DisplayPort OSD)                  |
|  • UART2    : ExpressLRS 2.4GHz Receiver (CRSF Protocol)                  |
|  • UART3    : GPS Module (U-blox SAM-M10Q @ 115200 baud)                 |
|  • I2C1     : Compass (SCL / SDA for QMC5883L / IST8310)                  |
|  • 5V / 9V  : High-power BEC for Camera, VTX, Servo, and GPS              |
+---------------------------------------------------------------------------+
```

### Motor Direction & Numbering (INAV Multirotor Quad-X Convention)
* **Motor 1**: Rear Right (CCW)
* **Motor 2**: Front Right (CW)
* **Motor 3**: Rear Left (CW)
* **Motor 4**: Front Left (CCW)

---

## 4. Pre-Flight Physical Checks
1. **Spar Rigidity**: Hold the fuselage firmly and check each wing for torsional play. There should be zero wobble along the 6mm carbon spars.
2. **Propeller Clearance**: Rotate the propellers by hand to confirm at least 15mm clearance from the fuselage and landing pads.
3. **Center of Gravity (CG)**:
   * Balance the aircraft with battery and FPV gear installed.
   * Adjust the battery position on `Battery Plate` until the aircraft balances neutrally without pitching forward or backward.

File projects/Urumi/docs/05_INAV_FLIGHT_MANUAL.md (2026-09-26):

# ✈️ INAV Hybrid VTOL Flight Manual & Tuning Guide

> **Flight Characteristics Reference**: Derived from real prototype flight logs and crash incident analysis ([`06_DESIGNER_FLIGHT_LOGS_AND_VIDEO_TRANSCRIPTS.md`](06_DESIGNER_FLIGHT_LOGS_AND_VIDEO_TRANSCRIPTS.md)).

---

## 1. Principles of Operation

Urumi is an unconventional hybrid aircraft:
* **In Hover**: It functions as an agile Quad-X multirotor, taking off and landing vertically.
* **In Forward Flight**: It tilts 90° forward onto its four 22° dihedral wings. Once the aircraft reaches approximately **70–80 km/h**, the wings generate enough aerodynamic lift to support the entire vehicle.
* **No Control Surfaces**: Unlike conventional aeroplanes, Urumi has **no ailerons, no elevators, and no rudder**. Attitude, banking, pitching, and yawing in forward flight are produced entirely through **differential motor thrust**.

```
Hover Mode (Quad-X)               Transition Phase                Forward Wing Flight
   [Motors ↑ Thrust]            [Pitch Forward ~45°]              [Wings Generate Lift]
   Camera @ 90°                  Camera @ 45°                      Camera @ 0°
   Takeoff & Landing             Accelerate to 70-80 km/h          High Speed Cruise
```

---

## 2. INAV Dual-Mixer Configuration

INAV supports two independent mixer profiles, which allows switching between multirotor and forward-flight handling on a single switch.

### 2.1 Critical Installation Requirement
> ⚠️ **Important**: The flight controller must be installed flat in the **conventional aeroplane orientation**, with the FC arrow pointing toward the front nose of the aircraft.
> The multirotor mixer then applies a software orientation offset (90° pitch rotation). If the FC is physically installed in multirotor orientation, the forward-flight mixer and horizon level calculations will fail.

---

### 2.2 The Two Mixer Profiles

#### Mixer Profile 2: Vertical / Multirotor Mode (Hover)
* **Configuration**: Standard Quad-X multirotor mixer.
* **Camera Servo**: Commanded to approximately **90° down** relative to the fuselage (which points straight at the natural ground horizon during vertical hover).
* **Used for**:
  * Vertical take-off
  * Low-speed manoeuvring
  * Stationary hovering
  * Vertical spot landings

#### Mixer Profile 1: Forward-Flight Mode (Aeroplane)
* **Configuration**: Custom differential-thrust aeroplane mixer.
* **Axis Swapping**:
  * In forward flight, what was previously multirotor **Roll** becomes aerodynamic **Yaw** (differential thrust between left and right wing pairs).
  * What was previously multirotor **Yaw** becomes aerodynamic **Roll**.
* **Camera Servo**: Commanded to **0° (pointing straight out the nose)**.
* **Used for**: High-speed, efficient winged cruising.

---

## 3. 3-Position Flight-Mode Switch Setup

Assign a 3-position switch on your RC transmitter (e.g. Channel 8 / Aux 4):

| Switch Position | Active Mixer Profile | Camera Tilt Angle | Flight Phase & Pilot Instructions |
| :---: | :---: | :---: | :--- |
| **Position 1 (High)** | **Mixer Profile 2** (Multirotor) | **90°** (Hover View) | **Vertical Take-off & Hover**: Aircraft stands vertically. Take off like a normal quadcopter. |
| **Position 2 (Mid)** | **Mixer Profile 2** (Multirotor) | **45°** (Intermediate) | **Acceleration & Transition**: The aircraft remains under quadcopter control, but the camera tilts to 45°. Push the pitch stick forward to build airspeed to 70–80 km/h while maintaining clear horizon sight. |
| **Position 3 (Low)** | **Mixer Profile 1** (Wing Mode) | **0°** (Forward View) | **Forward Aeroplane Flight**: Switch active. Wings produce lift; fly using combined roll and yaw differential thrust. |

```mermaid
stateDiagram-v2
    [*] --> HOVER_MODE: Arm in Switch Pos 1
    HOVER_MODE: <b>Vertical Hover (Multirotor Profile 2)</b><br/>Camera Tilt: 90° Down<br/>Vertical Take-off & Climb
    
    HOVER_MODE --> TRANSITION: Pitch Forward & Switch to Pos 2
    TRANSITION: <b>Acceleration (Multirotor Profile 2)</b><br/>Camera Tilt: 45°<br/>Build forward airspeed to 70–80 km/h
    
    TRANSITION --> WING_CRUISE: Switch to Pos 3 (Airspeed > 70 km/h)
    WING_CRUISE: <b>Aeroplane Cruise (Wing Profile 1)</b><br/>Camera Tilt: 0° Forward<br/>Wings carry lift; differential thrust steering
    
    WING_CRUISE --> DECEL: Switch to Pos 2 & Throttle Back
    DECEL: <b>Deceleration & Flare</b><br/>Airspeed drops below 30 km/h
    
    DECEL --> HOVER_MODE: Switch to Pos 1
    HOVER_MODE --> [*]: Vertical Spot Landing on Rear Pads & Disarm
```

---

## 4. Piloting Dynamics & Handling Insights

### 4.1 Roll Authority & Coordinated Turns
Because Urumi has no physical ailerons, rolling with the roll stick alone produces a very wide, sluggish turning radius.
* **Always fly coordinated turns**: Combine roll and yaw stick inputs simultaneously. This commands differential thrust across the four motor nacelles to carve crisp, tight turns.

### 4.2 Flat Yaw Turns
One of Urumi’s most distinctive manoeuvres is a **flat yaw turn**:
* In forward flight, applying yaw alone causes the left or right motor pairs to change speed, rotating the aircraft around its vertical axis with virtually zero bank angle.
* This produces a stable, pan-camera effect similar to a gimbal-stabilized camera drone flying at high speed.

### 4.3 Passive Weathercock Stability
The large rear fuselage and vertical fin profile act like a weather vane in windy conditions. The aircraft naturally tends to align its nose into the wind, aiding heading stability during hover.

---

## 5. Landing Procedure & Crash Prevention (Lessons Learned)

In initial flight testing, an accidental crash occurred due to pilot disorientation:
> *"The pilot believed the camera was tilted to 45°, when it was actually at 0°. Misjudging the aircraft's attitude, the pilot entered a steep descent in Acro mode, expecting the plane to recover like a lightweight racing drone. The mass, drag, and wing aerodynamics delayed the pull-out, resulting in a nose-first impact."*

### Safe Recovery & Landing Protocol:
1. **Never attempt to land in forward-flight Acro mode.**
2. **Step 1 (Deceleration)**: Flip the 3-position switch from **Position 3** back to **Position 2** (Camera moves to 45°, quadcopter mixer engages). Pull back gently on pitch to bleed off forward speed.
3. **Step 2 (Establish Hover)**: Once forward airspeed drops below 30 km/h, flip the switch to **Position 1** (Camera moves to 90° hover view). The aircraft will settle into a stable vertical hover.
4. **Step 3 (Vertical Touchdown)**: Descend smoothly like a quadcopter onto its 4 landing pads.
5. **OSD Safety Indicators**: Ensure your FPV On-Screen Display (OSD) shows:
   * Current Mixer Profile (`PROF 1` / `PROF 2`)
   * Camera tilt angle indicator
   * Artificial horizon / attitude ladder
   * GPS Groundspeed and Altitude

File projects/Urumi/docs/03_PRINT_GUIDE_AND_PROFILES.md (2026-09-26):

# 🖨️ 3D Printing Guide & Master Slicer Profiles

This guide translates the original spreadsheet data (`Urumi.ods`) into actionable presets for **Bambu Studio**, **OrcaSlicer**, and **PrusaSlicer** running on a Bambu Lab P1S/X1C/A1 (or any 200×200×220mm+ 3D printer).

---

## 1. Master Print Profiles Overview

All parts are sliced at **0.20 mm Layer Height**. Create the following profiles in your slicer:

| Profile Name | Layer Height | Wall Loops | Top Shells | Bottom Shells | Base Infill | Infill Pattern | Target Material |
| :--- | :---: | :---: | :---: | :---: | :---: | :---: | :--- |
| **Profile A** | 0.20 mm | 1 | 3 | 3 | 0% | Gyroid | PLA / PLA+ / ePLA-ST |
| **Profile B** | 0.20 mm | 2 | 4 | 4 | 0% | None | PLA / PLA+ / ePLA-ST |
| **Profile C** | 0.20 mm | 3 | 5 | 5 | 0% | None | PLA / PLA+ / ePLA-ST |
| **Profile D (Solid)** | 0.20 mm | 3 | 5 | 5 | 100% | Rectilinear / Aligned | PLA / PLA+ (Crucial for Motor Mounts) |
| **Profile LW (Canopy)**| 0.20 mm | 4 (or 2 in PLA) | 2 | 2 | 10% | Gyroid | Foaming PLA-LW / ASA-Aero (or PLA Basic) |

---

## 2. Complete Parts Slicing Table (from `Urumi.ods`)

Total Estimated Print Time: **~26 hours 30 minutes** | Total Plastic Weight: **~571 grams**

| Subfolder | Part File Name | Profile | Infill % | Print Time (P1P/P1S) | Weight | Special Modifiers & Slicer Rules |
| :--- | :--- | :---: | :---: | :---: | :---: | :--- |
| `01_Fuselage/` | `Fuselage 1.3mf` | **B** | 0% | ~00:47 | 18g | No infill, no supports. |
| `01_Fuselage/` | `Fuselage 2.3mf` | **A** | 4% | ~03:02 | 58g | **Set 8 top layers** for canopy latch rigidity. 4% Gyroid infill. |
| `01_Fuselage/` | `Fuselage 3.3mf` | **C** | 0% | ~01:01 | 35g | No infill, 3 walls, 5 top/bottom layers. |
| `01_Fuselage/` | `Fuselage 4.3mf` | **A** | 5% | ~02:55 | 53g | 5% Gyroid infill. |
| `02_Wings/` | `Wing 1-2.3mf` (Left 1) | **A** | 3% | ~03:10 | 58g | 1 wall loop, 3% Gyroid infill. Print 1 as-is. |
| `02_Wings/` | `Wing 1-2.3mf` (Right 2) | **A** | 3% | ~03:10 | 58g | **Mirror in slicer (X-axis)** to produce Wing 2. |
| `02_Wings/` | `Wing 3-4.3mf` (Left 3) | **A** | 3% | ~03:10 | 58g | 1 wall loop, 3% Gyroid infill. Print 1 as-is. |
| `02_Wings/` | `Wing 3-4.3mf` (Right 4) | **A** | 3% | ~03:10 | 58g | **Mirror in slicer (X-axis)** to produce Wing 4. |
| `03_Nacelles_and_Mounts/`| `Nacelle 1-2.3mf` | **B** | 0% | ~01:02 | 30g | **Enable Tree Supports on build plate**. |
| `03_Nacelles_and_Mounts/`| `Nacelle 3-4.3mf` | **B** | 0% | ~01:02 | 30g | **Enable Tree Supports on build plate**. |
| `03_Nacelles_and_Mounts/`| `Motor mount 1-2-3-4.3mf` | **D** | 100% | ~01:09 | 48g | **Print 4 copies. Must be 100% solid infill** for motor screw retention! |
| `03_Nacelles_and_Mounts/`| `Pad 1.3mf` | **C** | 0% | ~00:15 | 8g | Landing pad. 3 walls, 5 top/bottom. |
| `03_Nacelles_and_Mounts/`| `Pad 2.3mf` | **C** | 0% | ~00:15 | 7g | Landing pad. |
| `03_Nacelles_and_Mounts/`| `Pad 3.3mf` | **C** | 0% | ~00:15 | 7g | Landing pad. |
| `03_Nacelles_and_Mounts/`| `Pad 4.3mf` | **C** | 0% | ~00:15 | 7g | Landing pad. |
| `04_Internal_Plates/` | `Battery Plate.3mf` | **A** | 8% | ~00:19 | 11g | **Modifier**: Set 3 wall loops, 8% Gyroid infill. |
| `04_Internal_Plates/` | `FC Plate.3mf` | **A** | 8% | ~00:15 | 5g | **Modifier**: Set 3 wall loops, 8% Gyroid infill. |
| `04_Internal_Plates/` | `Servo Plate.3mf` | **A** | 8% | ~00:10 | 5g | **Modifier**: Set 3 wall loops, 8% Gyroid infill. |
| `04_Internal_Plates/` | `Camera mount.3mf` | **C** | 0% | ~00:36 | 8g | **Enable Supports** for camera pivot ears. |
| `05_Canopy/` | `Canopy 1.3mf` | **LW** | 10% | ~00:32 | 8g | 4 walls, 2 bottom, 2 top, 10% Gyroid (if PLA: 1 wall, 5% infill). |
| `05_Canopy/` | `Canopy 2.3mf` | **LW** | 10% | ~00:24 | 5g | 4 walls, 2 bottom, 2 top, 10% Gyroid (if PLA: 1 wall, 5% infill). |
| `05_Canopy/` | `Canopy locks.3mf` | **C** | 0% | ~00:14 | 4g | Print 2 sets. |

---

## 3. Wing Mirroring Instructions

The wings on Urumi are perfectly symmetrical left-to-right:
1. In Bambu Studio, import `3D_Print_Files/02_Wings/Wing 1-2.3mf`.
2. Slice and print your first copy (this is **Wing 1**).
3. Right-click the model on the virtual build plate -> select **Mirror** -> click **X Axis**.
4. Slice and print this mirrored part (this is **Wing 2**).
5. Repeat the exact same procedure for `Wing 3-4.3mf` to produce **Wing 3** (as-is) and **Wing 4** (mirrored).

---

## 4. Bed Placement & Orientation

Refer to the visual guides located in [`media/slicer_placement/`](../media/slicer_placement):
* `Fuselage 1.jpg`, `Fuselage 2.jpg`, `Fuselage 3.jpg`, `Fuselage 4.jpg` show the exact standing orientation on the build plate.
* Always orient tall fuselage parts standing vertically with the flat mating flange down on the plate.
* Use a brim (5mm–8mm) on `Fuselage 1` and `Fuselage 4` to prevent tall print wobbling on high-speed beds.

---

## 5. Bambu Lab P1S Recommended Print Settings

* **Nozzle**: 0.4 mm Stainless or Hardened Steel.
* **Plate**: Textured PEI Plate (clean with warm water and dish soap before large wing prints).
* **Printing Temperature (PLA Basic / PLA+)**: **230°C – 235°C** (The designer explicitly notes that high temperatures are required to ensure maximum layer bonding).
* **Bed Temperature**: 55°C – 60°C.
* **Chamber**: Door slightly ajar or top glass lifted for PLA to avoid heat creep during 3+ hour prints.
* **Cooling Fan**: 50%–70% for thin walls; reduce to 20% on the first 5 layers.

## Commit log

2026-09-26 feat: initialize AeroBlades repository with unified 3D-printed FPV cruiser fleet and VTOL systems
    [Battery Plate.3mf, Battery Plate.step, Battery plate.3mf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]
2026-09-26 feat: add comprehensive fleet best practices suite for materials, 3D printing, electronics, and avionics
2026-09-26 docs: expand Guide 03 into comprehensive powertrain engineering manual with sizing formulas and airframe recipes
